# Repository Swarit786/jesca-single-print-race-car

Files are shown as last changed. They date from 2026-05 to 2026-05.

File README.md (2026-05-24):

# JESCA — Single-Print Movable Mini Car

A fully functional miniature race car designed and manufactured as a **single printed part** — no assembly, no hardware, no post-print joining. Designed for an Additive Production seminar race championship where cars were released down a curved ramp and scored by distance traveled relative to print weight.

**Team:** JESCA (5 members) | **Tools:** Fusion 360, SolidWorks | **Printer:** Prusa MINI+ | **Year:** 2023

---

## Challenge

Design a movable miniature car that:
- Is printed as **one single part** — no assembly allowed
- Fits within **75 × 40 × 50 mm**
- Weighs at least **10 g**
- Has all four wheels rotating freely after printing
- Scores highest on: **Car Performance = Distance (m) ÷ Print weight (g)**

The scoring formula made weight optimization just as critical as aerodynamics and rolling performance. A lighter car that rolls the same distance outscores a heavier one.

---

## The Core Engineering Problem

Making wheels that rotate freely inside a single-print part requires solving three problems simultaneously:

**1. Clearance between axle and wheel bore** — tight enough to keep wheels aligned, loose enough to rotate without friction locking after cooling and shrinkage.

**2. Wheel retention** — no snap-fits, no screws, no clips. The axle geometry itself must prevent the wheels from sliding off.

**3. Printability** — the clearance gaps between moving parts must survive the print process without fusing. Layer adhesion across a 0.28 mm gap behaves differently at different orientations.

---

## Axle Design

The axle is the critical component. Before the final car was printed, an **axle test phase** was conducted — up to 5 different axle designs were printed and evaluated within a 40 × 40 × 40 mm design space to find the optimal clearance and geometry.

The final axle uses a **conical flange design**: the wheel disc sits inside a tapered collar that widens outward, keeping the wheel captured on the axle without any additional hardware.

| Parameter | Front axle | Rear axle |
|---|---|---|
| Wheel diameter | Ø 20 mm | Ø 25 mm |
| Shaft diameter | Ø 20 mm | Ø 25 mm |

The 0.28 mm radial clearance was selected based on axle test results to allow free rotation while minimising lateral wobble.

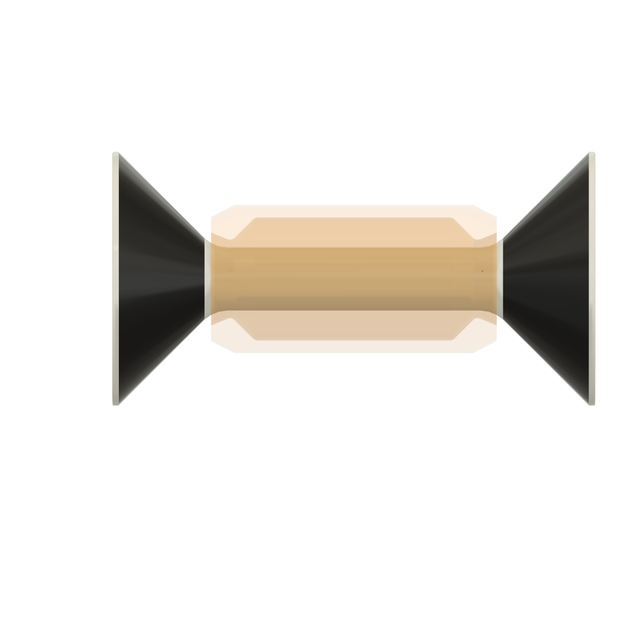
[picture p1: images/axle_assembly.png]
Axle assembly render

*Isolated axle render — conical flanges retain wheels without hardware*

---

## Printed Car

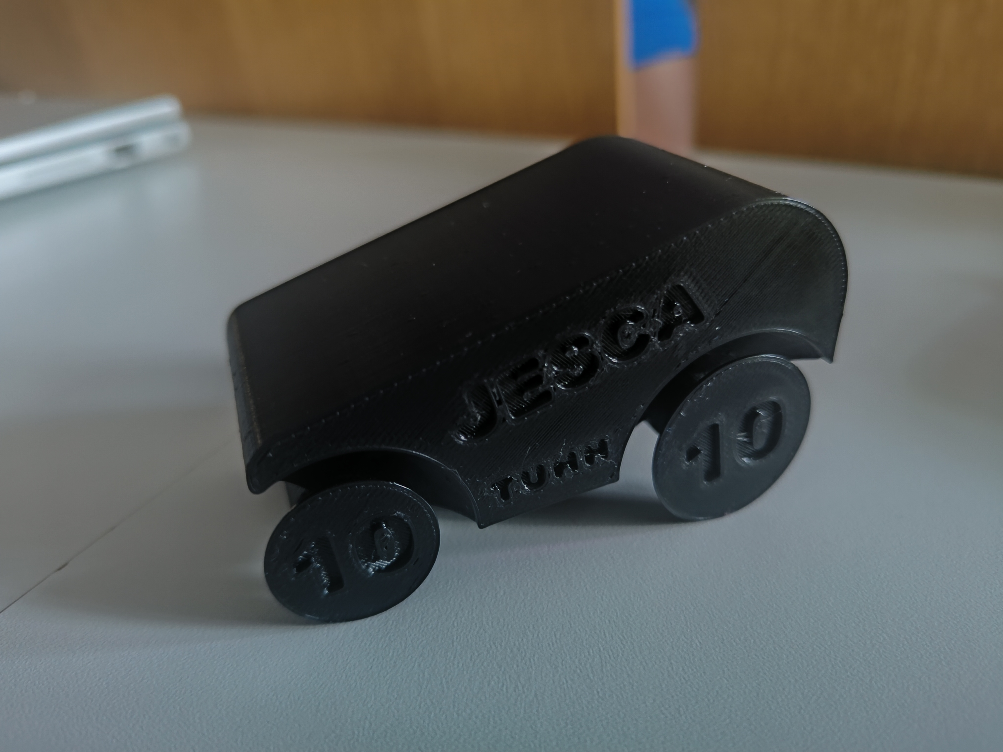
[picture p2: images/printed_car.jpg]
Printed car

*The final printed JESCA car — single black PLA part, photographed on championship day. Layer lines visible on the body, "JESCA" and group number "10" embossed directly into the geometry. The gap between wheel and body is the 0.28 mm clearance that allows free rotation.*

---

## CAD Renders

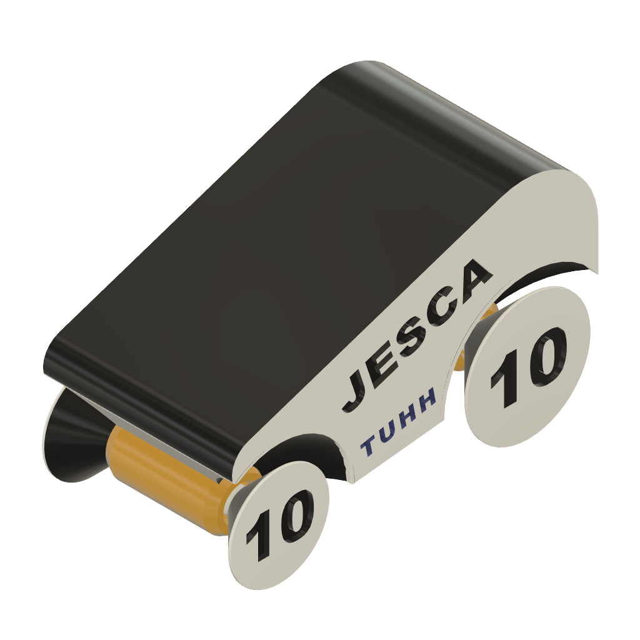
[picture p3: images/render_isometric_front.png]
Isometric front view

*Full assembly — body, wheels, and axles as a single unified geometry. "10" embedded in wheel face = team group number*

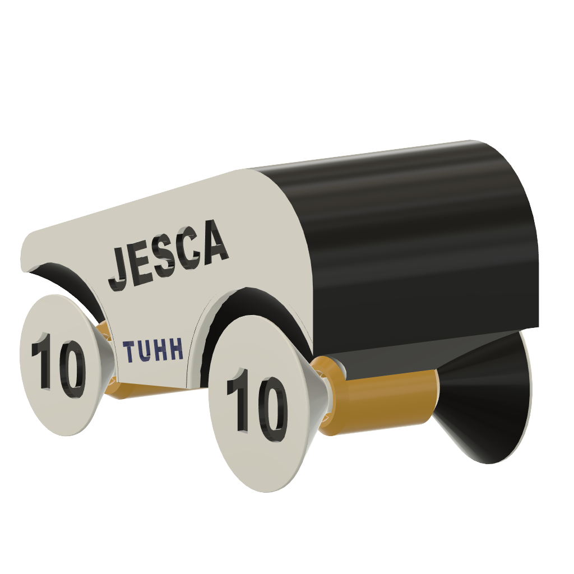
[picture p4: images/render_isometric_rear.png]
Isometric rear view

*Rear view — front axle and wheel clearance gap visible*

---

## Print Strategy

### Orientation

The car was printed lying on its **X axis** — the axle runs parallel to the print bed. This was a deliberate DfAM decision:

- Axle cross-section prints as a continuous perimeter loop at each layer, giving full circumferential strength
- Clearance gaps between axle and wheel bore are maintained consistently layer by layer
- Avoids printing the axle vertically, which would place wheel loads against the weakest direction (between layers)

### Slicer Preview

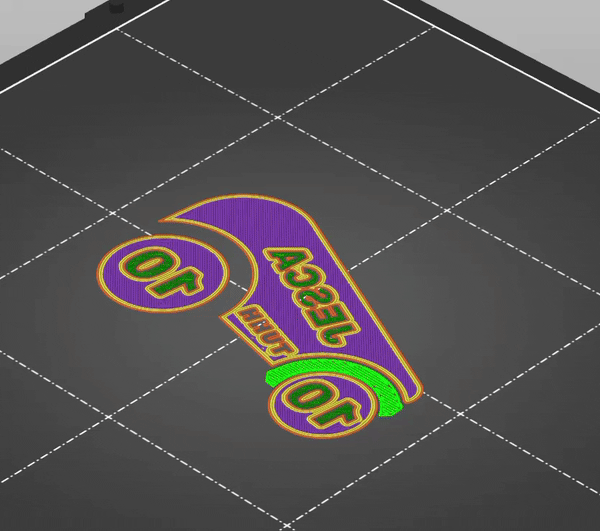
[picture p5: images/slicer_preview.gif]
Slicer preview


*Prusa Slicer preview showing print orientation and layer structure — green areas are auto-generated supports for overhanging geometry, removed after printing*

### Print Parameters

| Parameter | Value |
|---|---|
| Printer | Prusa MINI+ |
| Layer height | 0.20 mm (Quality) |
| Infill pattern | Gyroid |
| Infill density | ≤ 15% |
| Supports | Added where needed |
| Print time | 1 h 26 min |

Gyroid infill at 15% was chosen for its isotropic strength properties — it distributes load evenly in all directions while keeping weight low, directly improving the performance score.

---

## Race Challenge

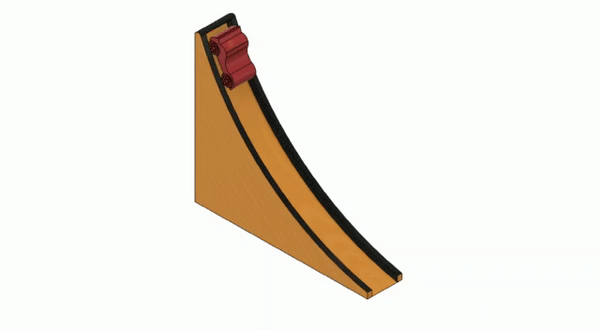
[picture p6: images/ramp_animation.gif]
Ramp animation


*Championship ramp — 260 mm run, 300 mm drop. Cars released from the top, scored by distance divided by total print weight (car + supports)*

The ramp geometry meant the car needed to handle both the initial acceleration on the curved section and maintain momentum across a flat surface. Rolling resistance (axle friction, wheel alignment) directly affected final distance.

---

## DfAM Principles Applied

| Principle | How it was applied |
|---|---|
| Single-part design | Wheels, axles, and body unified into one printable geometry |
| Clearance engineering | 0.28 mm radial gap — calibrated through test prints |
| Print orientation | X-axis orientation for axle strength and gap consistency |
| Lightweight structure | Gyroid infill at ≤15% to minimise print weight |
| Embedded geometry | Group number "10" embossed directly into wheel face |
| Iterative testing | Axle test phase before committing to final car design |

---

## Engineering Drawings

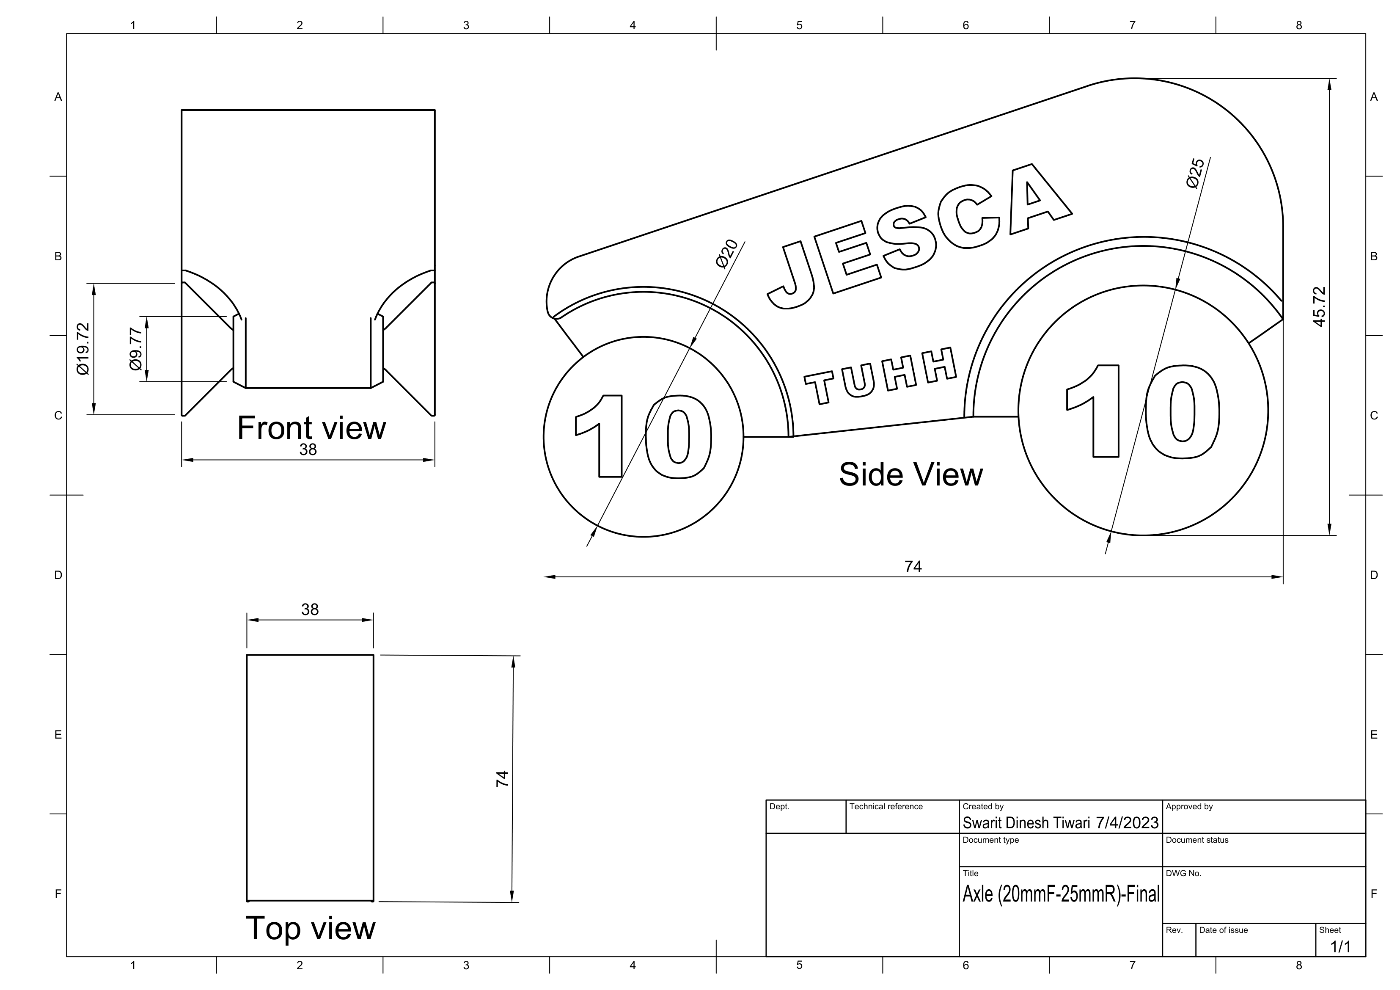
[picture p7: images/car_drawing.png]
Car drawing

*Car body technical drawing — overall dimensions within the 75 × 40 × 50 mm design space constraint*

Full PDF drawings available in the `drawings/` folder.

---

## Files

- `car_assembly.step` — Full single-part CAD model
- `drawings/car_drawing.pdf` — Car body technical drawing
- `images/slicer_preview.gif` — Prusa Slicer layer preview animation
- `images/ramp_animation.gif` — Championship ramp simulation

---

## Team

JESCA — a team of 5 M.Sc. Mechanical Engineering students. Team name formed from the initials of all five members.

## License

MIT License

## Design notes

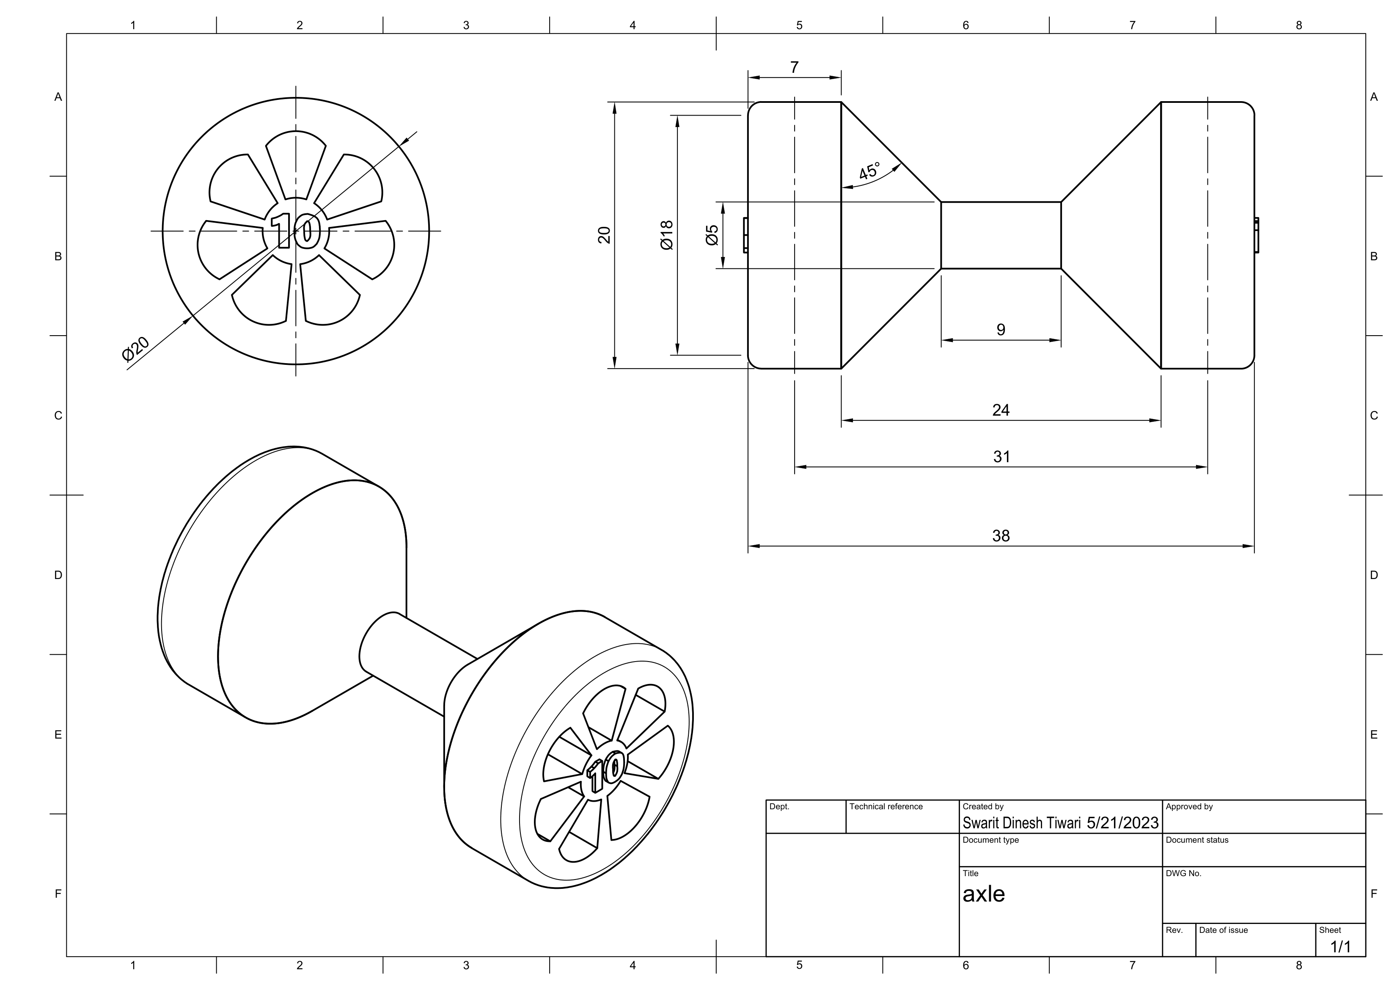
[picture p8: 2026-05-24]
images/axle_drawing.png

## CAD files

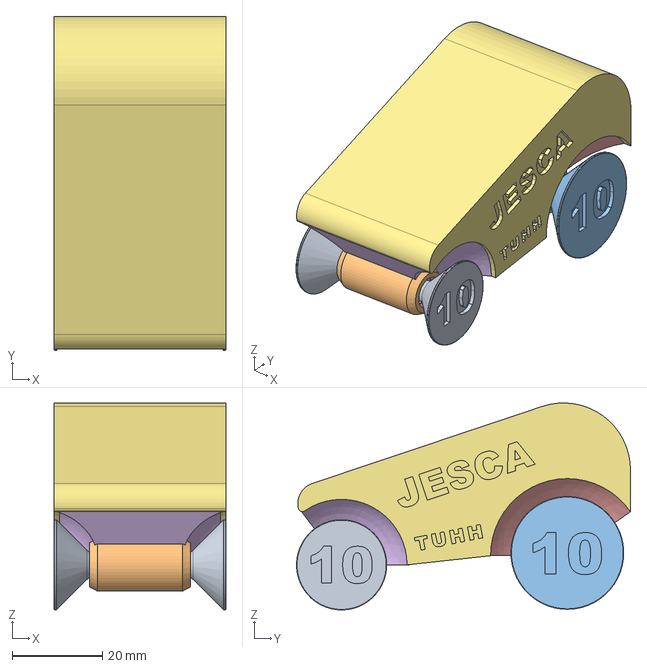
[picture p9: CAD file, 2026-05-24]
car_assembly.step
38.0 x 74.0 x 45.9 mm

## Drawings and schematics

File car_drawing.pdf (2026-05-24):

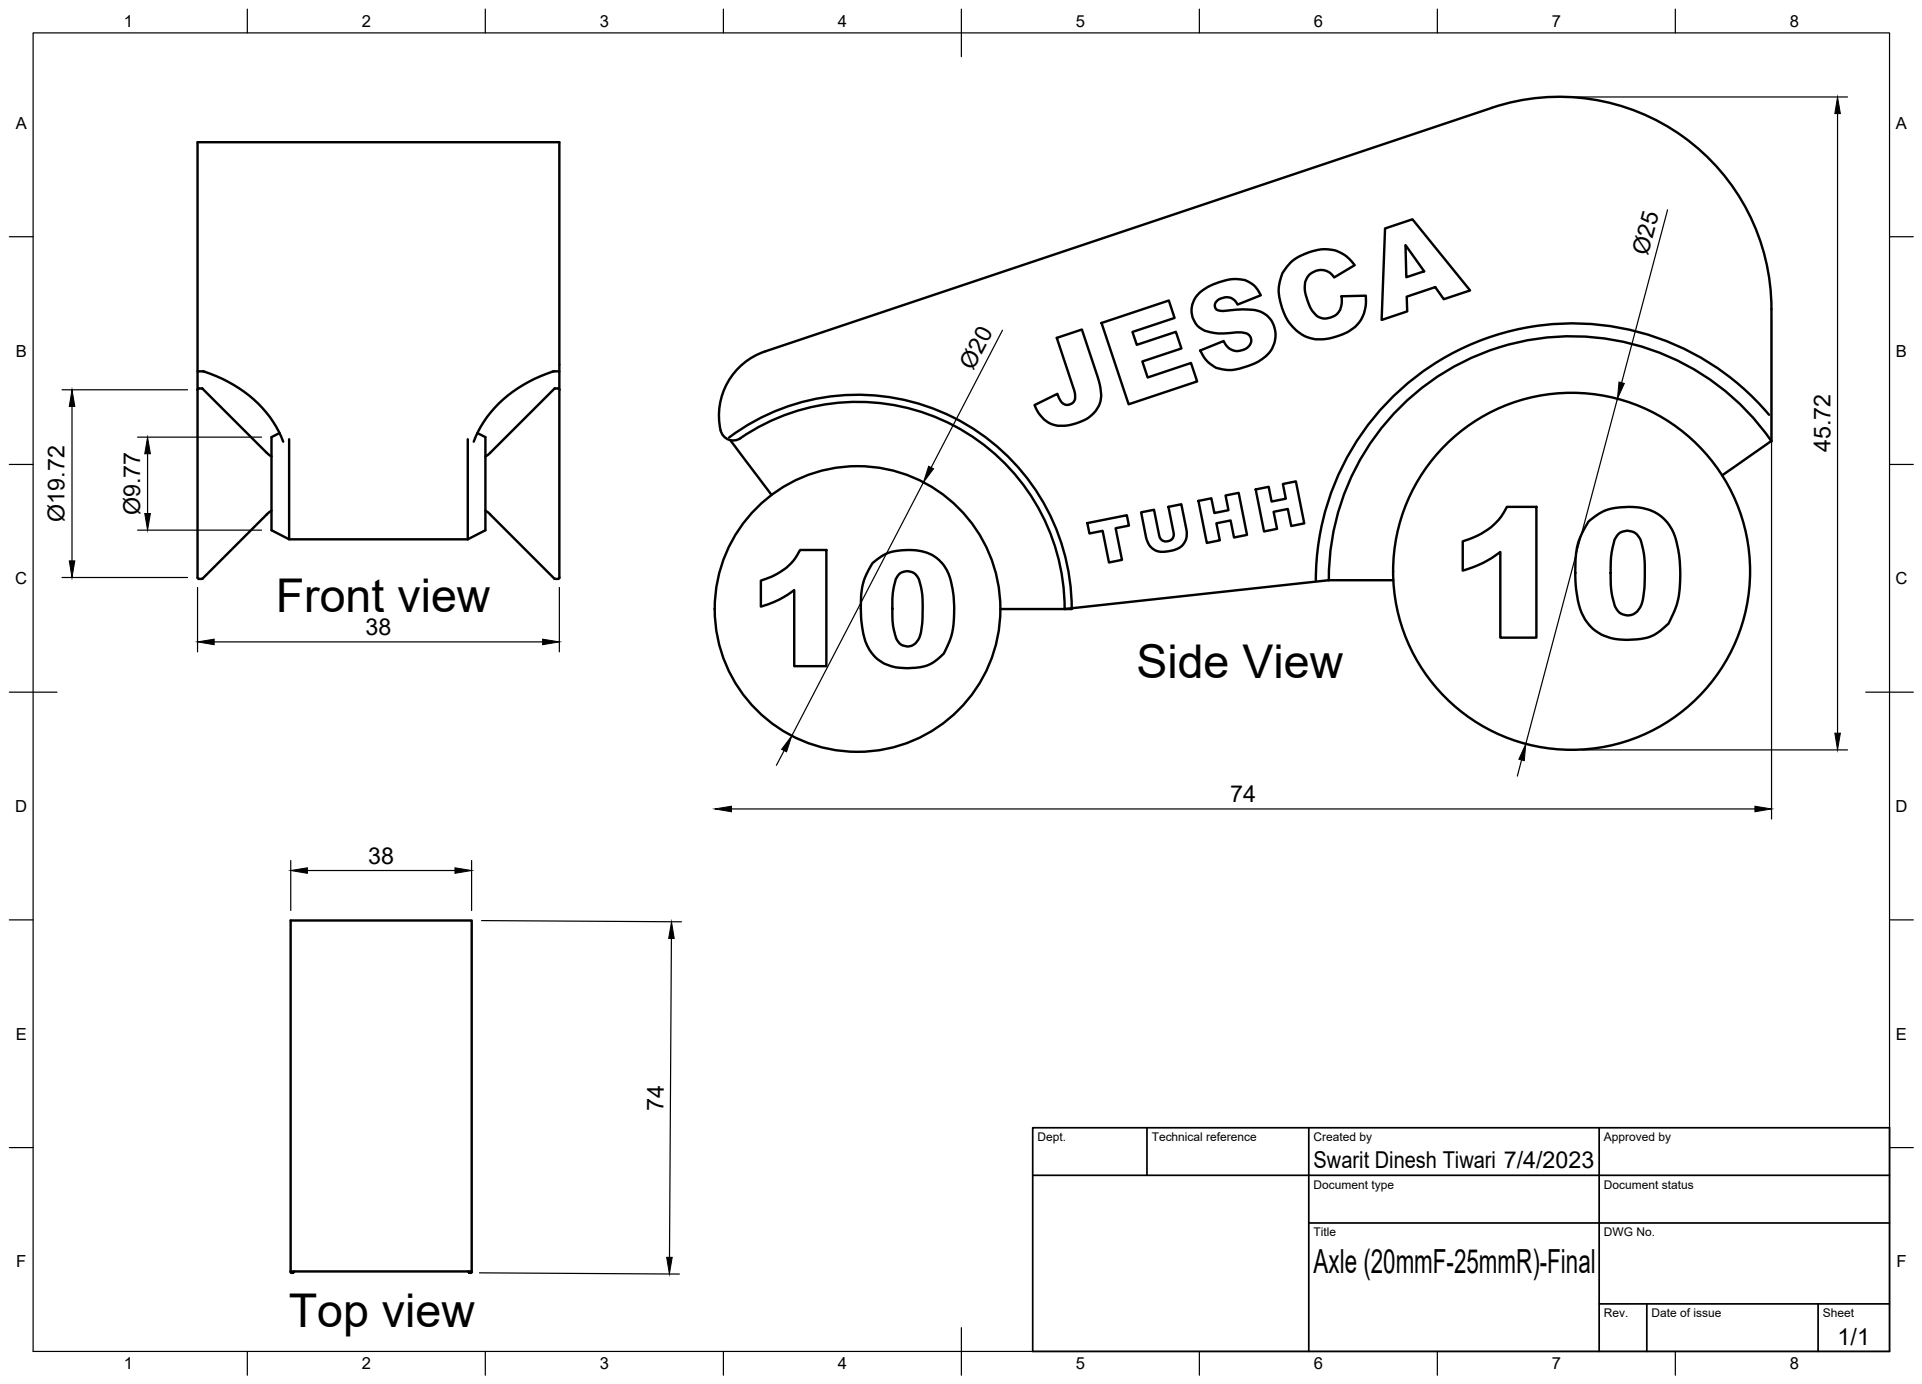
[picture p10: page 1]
Title; DWG No.; Rev.; Date of issue; Sheet; Axle (20mmF-25mmR)-Final; Front view; Side View; Top view

Dept. | Technical reference | Created by Swarit Dinesh Tiwari 7/4/2023 | Approved by

Document type | Document status
